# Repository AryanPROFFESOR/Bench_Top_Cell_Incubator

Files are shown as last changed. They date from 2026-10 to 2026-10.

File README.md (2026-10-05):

# Bench-Top Cell Incubator

**An automated stage-top incubator for live-cell imaging of stem cells: custom control PCB, rack-and-pinion plate carriage, firmware and PC dashboard.**

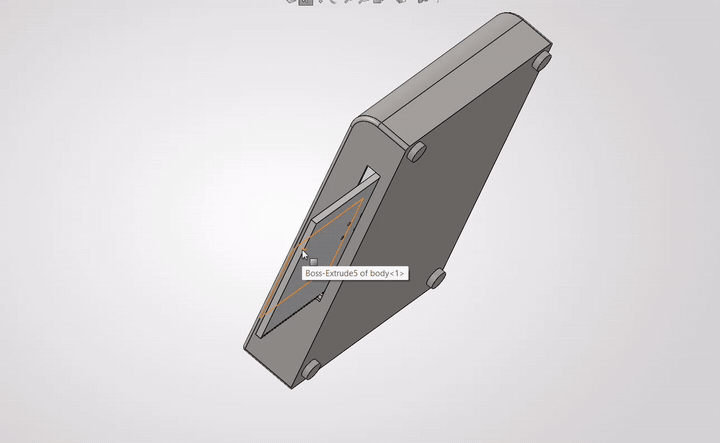
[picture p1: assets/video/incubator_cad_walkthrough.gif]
CAD walkthrough


<sub>SolidWorks walkthrough of the shell, chamber and ejecting tray (loops automatically). [Full-quality video](assets/video/incubator_cad_walkthrough_full.mp4).</sub>

## Contents

- [What this is](#what-this-is)
- [Project status](#project-status)
- [Mechanical design](#mechanical-design)
- [Electronics](#electronics)
  - [System architecture](#system-architecture)
  - [Sensors](#sensors-and-what-they-do)
  - [Communication protocols](#communication-protocols-and-interfaces)
  - [Pin map](#pin-map)
- [Software](#software)
- [Repository layout](#repository-layout)
- [Open questions for the lab](#open-questions-for-the-lab)
- [Fit with the internship brief](#fit-with-the-internship-brief)
- [Known limitations](#known-limitations)
- [Author](#author) · [License](#license)

## What this is

Live-cell time-lapse imaging needs cells held at physiological conditions (37 °C, 5 % CO2, high humidity) on the microscope stage for days.
Full-microscope enclosures are large and expensive. This project is a compact **stage-top incubator** that sits on the stage of an inverted microscope.

Its key feature is an **automated tray**: a motor-driven rack and pinion ejects and retracts a standard 96-well plate, so media changes or robotic liquid handling can happen without disturbing the chamber or the optical alignment.

It was built as a mechatronics and software project in support of an internship application (small cell incubator with temperature, CO2 and N2 control, automatic sample insertion and removal, and C++/Python control software).

## Project status

| Area | Status |
|---|---|
| Control PCB (schematic, DRC) | Complete |
| PCB layout | Routed; ground pour and file export pending |
| Temperature and humidity sensing | Designed |
| 5-channel servo output | Designed |
| Mechanical CAD (SolidWorks) | Almost done; final work waits on lab input (below) |
| Firmware and PC dashboard | Written, sensor maths unit-tested; hardware testing pending |
| CO2 and N2 control | Not on the PCB; assumed external for now |
| Physical build and biological validation | Planned: [validation plan](docs/test_plan.md) |

Full list in [docs/roadmap.md](docs/roadmap.md).

## Mechanical design

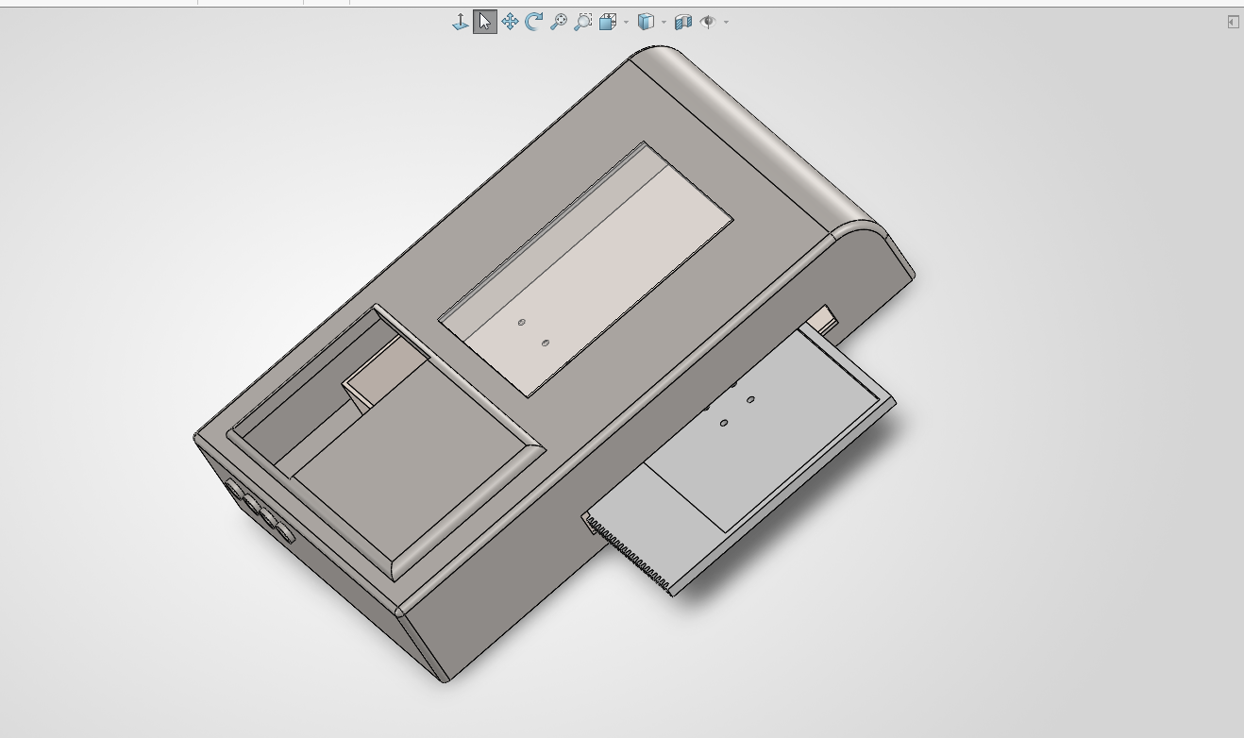
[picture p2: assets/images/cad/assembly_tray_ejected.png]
Assembly with tray ejected


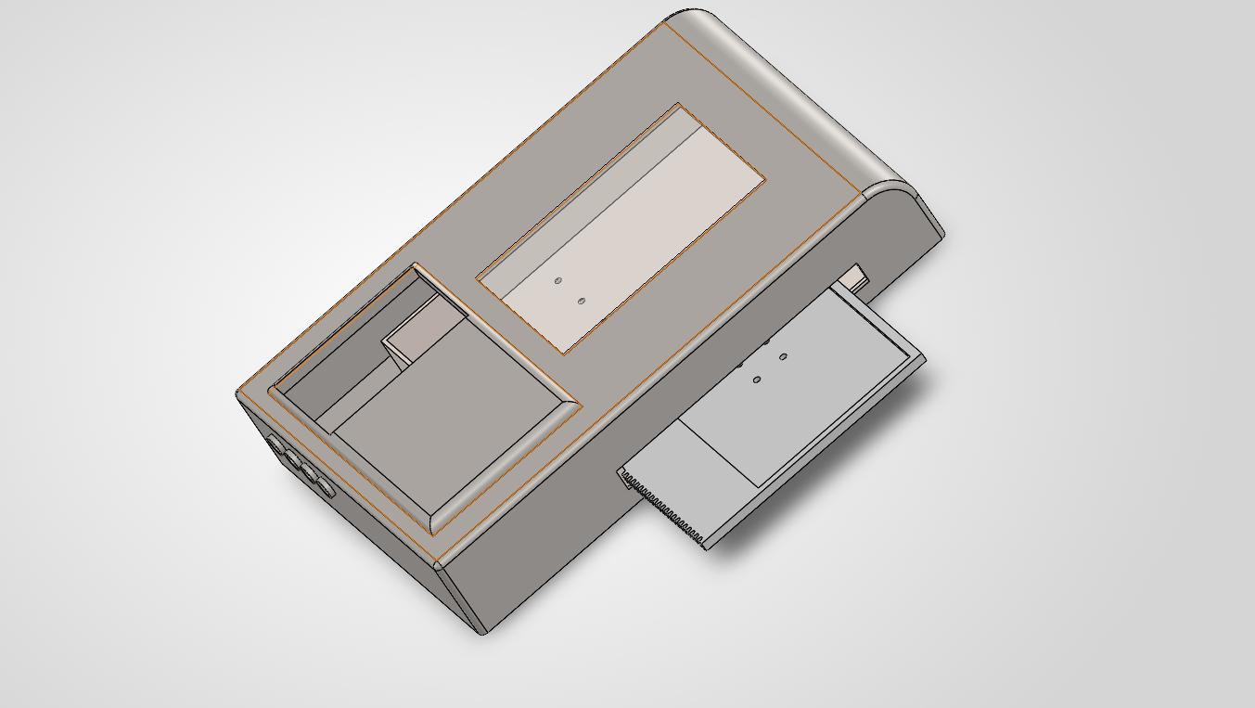
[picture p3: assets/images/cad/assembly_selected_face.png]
Shell with selected top face


| Rack on the carriage tray | Motor bracket and pinion |
|---|---|
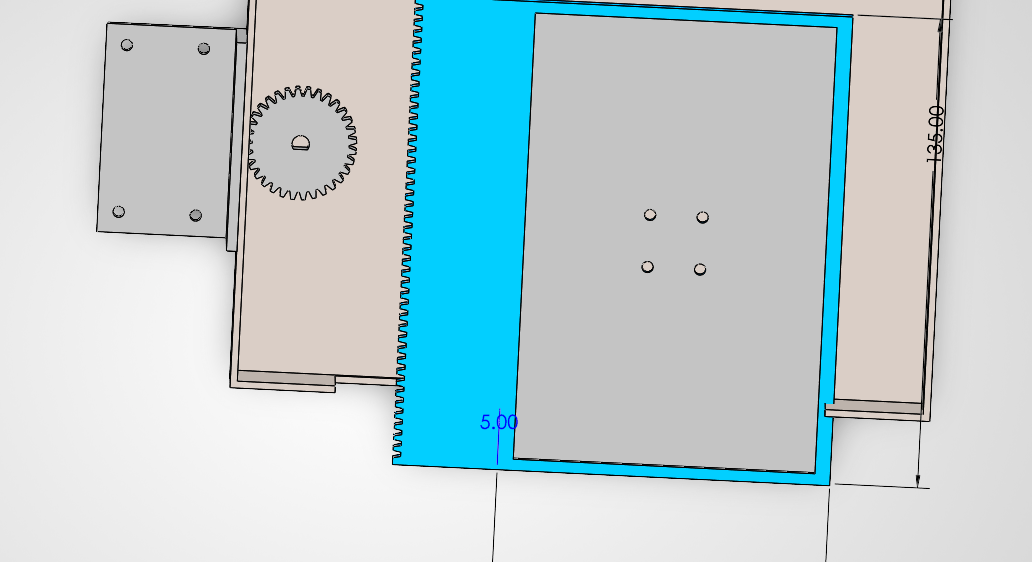
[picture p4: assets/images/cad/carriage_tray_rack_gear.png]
Tray and rack
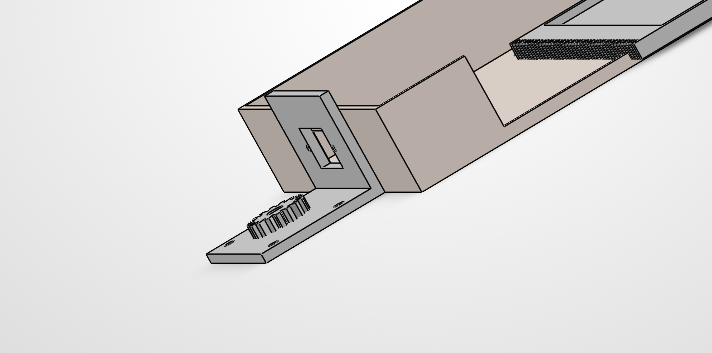
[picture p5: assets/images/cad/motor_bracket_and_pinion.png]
Bracket and pinion
|  |  |

- **Outer shell:** unibody enclosure with an offset viewing window for inverted microscopy, a lateral ejection port and an IEC power switch. An opaque "side-car" cavity keeps the drive and electronics apart from the humid zone.
- **Inner chamber and tray:** the tray holds a 96-well plate and has a linear rack along one edge.
- **Drive:** a pinion meshes with the rack. A motor bracket holds the actuator away from the heated zone.
- **Fabrication:** FDM printing. PETG or ABS for structure, nylon or POM for gears, and a 1 mm polycarbonate or glass window.

Details: [docs/mechanical.md](docs/mechanical.md).

## Electronics

| Routed layout | 3D render |
|---|---|
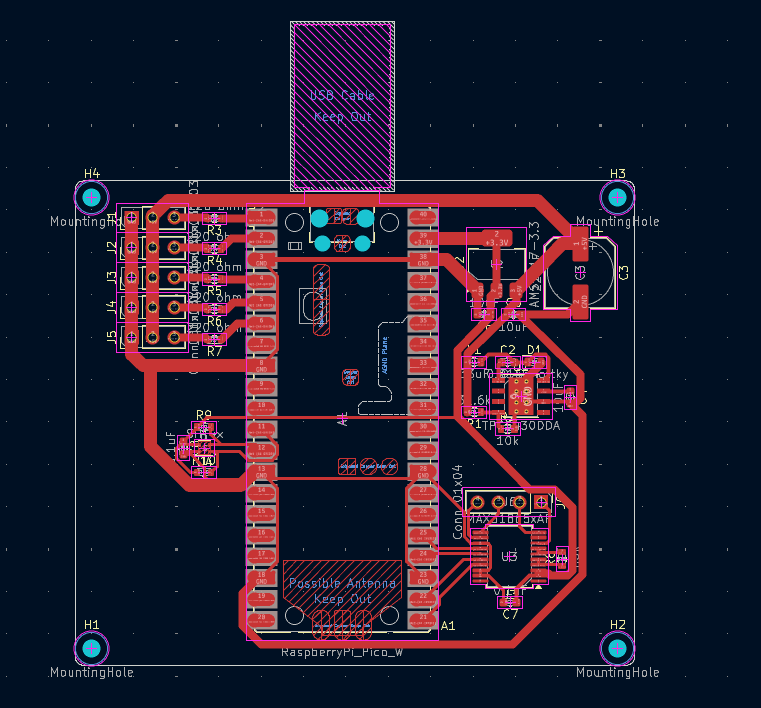
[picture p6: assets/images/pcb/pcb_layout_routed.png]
PCB layout
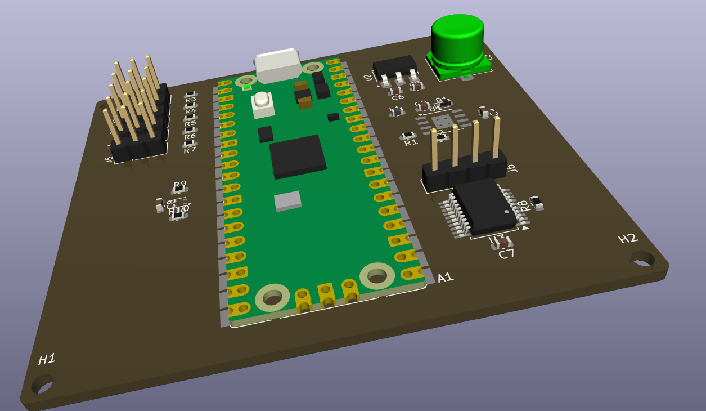
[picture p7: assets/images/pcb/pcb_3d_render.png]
PCB 3D
|  |  |

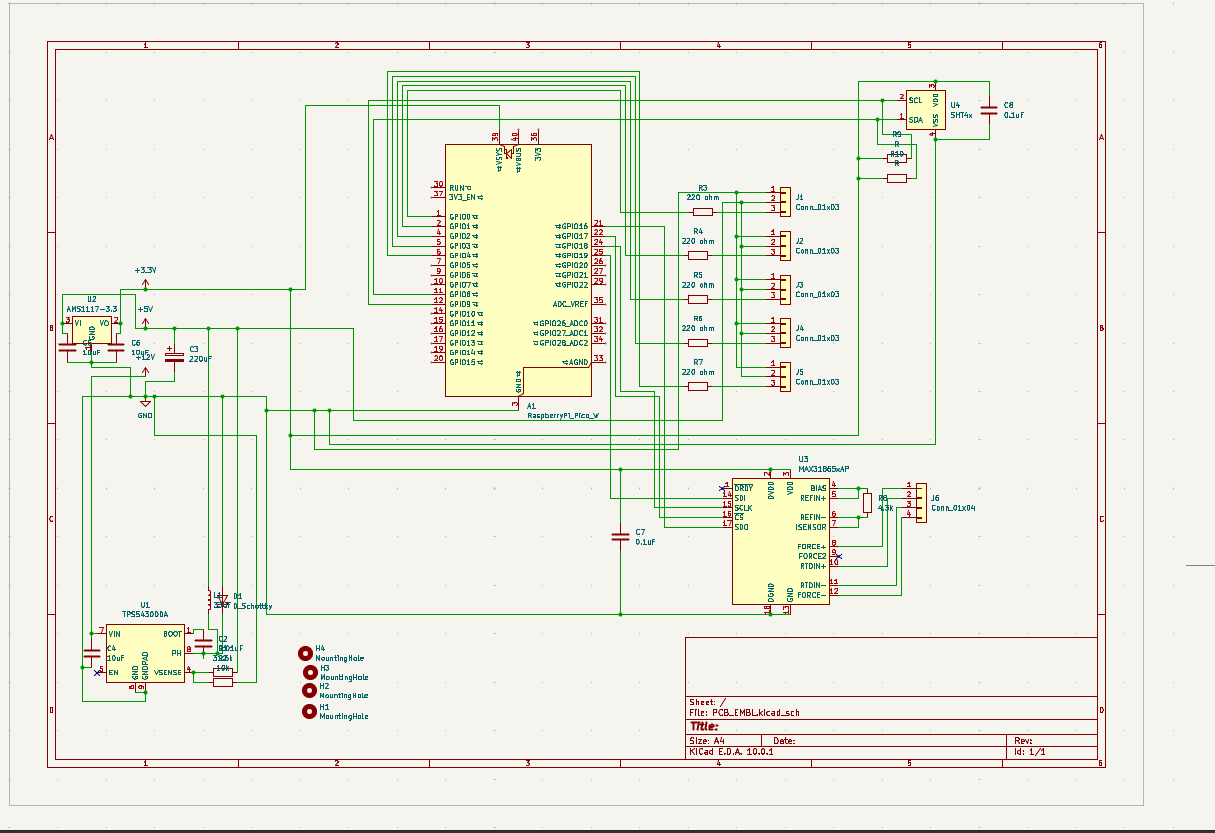
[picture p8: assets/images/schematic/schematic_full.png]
Schematic


The board is built around a **Raspberry Pi Pico W** and powered from 12 V DC through a two-stage supply: a TPS5430 buck converter (5 V, up to 3 A, for actuators) followed by an AMS1117 LDO (3.3 V, for logic and sensors). High-current switching nodes are kept away from the analog sensing area.

### System architecture

Solid arrows are implemented on the current board. Dashed arrows are planned or not yet implemented.

```mermaid
flowchart TB
    subgraph PWR["1. Power"]
        direction LR
        PSU["12 V DC supply<br/>(external)"] --> BUCK["TPS5430 buck<br/>12 V to 5 V, up to 3 A"]
        BUCK --> LDO["AMS1117 LDO<br/>5 V to 3.3 V"]
    end

    subgraph SENSE["2. Sensing"]
        direction TB
        PT["PT1000 probe<br/>4-wire, header J6"] -->|"analog resistance"| MAX["MAX31865<br/>RTD-to-digital"]
        SHT["SHT4x<br/>humidity + temperature"]
    end

    subgraph CTRL["3. Controller"]
        PICO["Raspberry Pi Pico W<br/>MicroPython firmware"]
    end

    subgraph ACT["4. Actuation"]
        SERVO["Servo headers J1 to J5<br/>J1 drives the rack-and-pinion tray"]
    end

    subgraph HOST["5. Host"]
        PC["PC dashboard<br/>PyQt5 + CSV log"]
    end

    subgraph EXT["Planned, not on this PCB"]
        direction TB
        CO2["CO2 sensor + gas control"]
        N2["N2 valve"]
        HEAT["Heater + driver stage"]
    end

    LDO -->|"3.3 V"| PICO
    LDO -->|"3.3 V"| MAX
    LDO -->|"3.3 V"| SHT
    BUCK -->|"5 V"| SERVO

    MAX <-->|"SPI0, GPIO16-19"| PICO
    SHT <-->|"I2C0, GPIO8/9, addr 0x44"| PICO
    PICO -->|"PWM 50 Hz, GPIO0-4"| SERVO
    PICO <-->|"USB serial, 115200 baud, JSON lines"| PC

    PICO -.->|"Wi-Fi telemetry (hardware ready, firmware pending)"| PC
    PICO -.->|"protocol TBD"| CO2
    PICO -.->|"GPIO / PWM"| N2
    PICO -.->|"PWM / on-off"| HEAT
```

### Sensors and what they do

| Sensor | Measures | Details |
|---|---|---|
| PT1000 RTD + MAX31865 | Chamber temperature (target 37.0 °C) | 4-wire ratiometric measurement removes lead-wire error; 4.3 kΩ 0.1 % reference resistor |
| SHT4x | Relative humidity (target about 95 %) and temperature | Digital and factory-calibrated, ±1.5 % RH typical |
| CO2 sensor (planned) | 5 % CO2 | Depends on the gas route |
| N2 / O2 (planned) | Hypoxia control | Depends on the gas route |

### Communication protocols and interfaces

| Link | Protocol | Pins / port | Settings and details |
|---|---|---|---|
| Pico W ↔ MAX31865 | **SPI** (mode 1: CPOL 0, CPHA 1) | SPI0: MISO GPIO16, CS GPIO17, SCK GPIO18, MOSI GPIO19 | 500 kHz in firmware (chip supports up to 5 MHz); 15-bit ADC read from RTD registers; 50 Hz mains filter enabled |
| PT1000 → MAX31865 | **Analog**, 4-wire Kelvin sensing | Header J6 (FORCE+, FORCE−, RTDIN+, RTDIN−) | Ratiometric against R8 = 4.3 kΩ; temperature from the Callendar-Van Dusen equation |
| Pico W ↔ SHT4x | **I2C** | I2C0: SDA GPIO8, SCL GPIO9 | Address 0x44; 100 kHz; 10 kΩ pull-ups (R9, R10) to 3.3 V; CRC-8 check on every reading |
| Pico W → servos | **PWM** | GPIO0 to GPIO4, headers J1 to J5 | 50 Hz, 500 to 2500 µs pulse; 220 Ω series resistor on each signal line |
| Pico W ↔ PC | **USB serial** (CDC virtual COM port) | Pico micro-USB | 115200 baud; Pico sends one JSON line per sample; PC sends text commands `EJECT`, `RETRACT`, `SET_TEMP <°C>` |
| Pico W ↔ network | **Wi-Fi** (on-board radio) | Antenna keep-out on the PCB | Hardware supports it; telemetry over Wi-Fi is not implemented yet |
| CO2 / N2 / heater | To be decided | Not on this PCB | Depends on the sensors, valves and driver chosen (see [roadmap](docs/roadmap.md)) |
| Power | **12 V DC → 5 V → 3.3 V** | 5 V rail for servos, 3.3 V for logic and sensors | Buck then LDO, so sensors are isolated from motor noise |

Example telemetry line sent by the firmware:

```json
{"t": 1767225600, "tray": "retracted", "setpoint_c": 37.0, "temp_c": 36.982, "heater": 0.0, "rh_pct": 94.6}
```

### Pin map

| Function | Pico W pin |
|---|---|
| SPI (MAX31865): MISO / CS / SCK / MOSI | GPIO16 / 17 / 18 / 19 |
| I2C (SHT4x): SDA / SCL | GPIO8 / 9 |
| Servo PWM, headers J1 to J5 | GPIO0 to GPIO4 (220 Ω series resistors) |

More in [docs/electronics.md](docs/electronics.md); parts list in [hardware/pcb/bom.csv](hardware/pcb/bom.csv); PCB documentation PDF in [hardware/pcb/docs/](hardware/pcb/docs/).

## Software

- **Firmware** (`firmware/pico/`, MicroPython): MAX31865 and SHT4x drivers, servo-driven tray eject/retract with a smooth ramp, a PID loop (heater output is optional because the board has no heater driver yet), and JSON telemetry over USB serial.
- **Dashboard** (`software/gui/`, PyQt5): live temperature and humidity, tray control, setpoint, CSV logging.
- **Tests** (`firmware/tests/`): the PT1000 conversion, SHT4x CRC and conversion, and PID clamping run on a PC.

```bash
# unit tests (no hardware needed)
python -m unittest discover firmware/tests

# flash firmware: copy firmware/pico/*.py to the Pico W (for example with mpremote or Thonny), then:
pip install -r software/requirements.txt
python software/gui/incubator_gui.py --port COM5      # or /dev/ttyACM0
```

Heads-up: the firmware and dashboard have not yet been run on the assembled hardware. Tray angles and PID gains in `config.py` and `main.py` are placeholders to calibrate.

## Repository layout

```text
assets/        images and the CAD walkthrough video (GIF + MP4)
docs/          electronics, mechanical, test plan, roadmap, design review notes
hardware/
  pcb/         KiCad project and schematic, BOM, PCB documentation PDF
  cad/         SolidWorks assembly and design proposal PDF
firmware/      MicroPython code for the Pico W, plus PC unit tests
software/      PyQt5 dashboard (and a placeholder for the image pipeline)
```

## Open questions for the lab

These three answers decide the final CAD ([details](docs/roadmap.md)):

1. Should the incubator be screwed to the microscope stage, or rest on it?
2. How are CO2 and N2 supplied: an existing external mixer (fittings only), or valves controlled by this device?
3. Should the control PCB live inside the side-car cavity, or in an external control box?

## Fit with the internship brief

| Requirement | Where it shows up here |
|---|---|
| Design a small incubator (temperature, CO2, N2) | Temperature and humidity sensing and the chamber design are done; CO2/N2 are scoped as external ([roadmap](docs/roadmap.md)) |
| Automatic sample insertion and removal | Rack-and-pinion tray CAD and servo tray control |
| Control software in C++ and Python | MicroPython firmware and a PyQt5 dashboard (C++/Arduino version is a possible port) |
| Electronics and soldering | Custom KiCad PCB with buck, LDO, RTD front-end and I2C sensor |
| 3D design and printing | SolidWorks assembly with an FDM print plan |
| Test with biological samples over days | [Validation plan](docs/test_plan.md) |
| Work with biologists | The open questions above are written for the lab |

Stepper motors: the current board drives hobby servos. A stepper-based tray drive is listed as the next step in the [roadmap](docs/roadmap.md).

## Known limitations

A self-review of the current schematic is in [docs/design_review_notes.md](docs/design_review_notes.md).

## Author

Aryan, ECE student at USICT. GitHub: [@AryanPROFFESOR](https://github.com/AryanPROFFESOR).

## License

[MIT](LICENSE)

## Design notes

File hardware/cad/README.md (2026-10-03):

# CAD (SolidWorks)

- `solidworks/Main_Incubator_Assembly.SLDASM` is the top-level assembly.
- An assembly file only references its parts. To open it in full, add the part files (`.SLDPRT`) into `solidworks/` next to it.
- Also export STEP and STL files for the shell, chamber, tray, bracket and gears so the design can be viewed and printed without SolidWorks.
- `Mechanical_Design_Proposal.pdf` has the design write-up.

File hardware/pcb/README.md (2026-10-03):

# Control PCB (KiCad 10)

- `kicad/PCB_EMBL.kicad_pro` and `kicad/PCB_EMBL.kicad_sch`: project and schematic.
- `docs/PCB_Hardware_Documentation.pdf`: component-by-component documentation.
- Layout images: `../../assets/images/pcb/`.

**Pending:** the routed board file `PCB_EMBL.kicad_pcb` is not in this repo yet. Save it from KiCad's PCB editor and copy it into `kicad/`, together with Gerbers and a BOM export (`File > Fabrication Outputs`).

Bill of materials: [`bom.csv`](bom.csv).

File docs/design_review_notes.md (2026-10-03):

# Design review notes (checklist for the next revision)

A self-review of the current schematic. Items are things to confirm or fix before ordering boards.

| # | Item | Why it matters |
|---|---|---|
| 1 | L1 is labelled `33uF` in the schematic; it should read 33 uH. | Wrong unit in the schematic value field. |
| 2 | L1 and D1 use 0603 footprints. | A 0603 inductor and diode cannot carry the buck's current at up to 3 A. Select a power inductor and a Schottky in a proper package (for example SMA/SMB) and update the footprints. Check values against the TPS5430 datasheet. |
| 3 | R9 and R10 (I2C pull-ups) have the value `R` in the schematic; the documentation says 10 kohm. | Set the value so the BOM is correct. |
| 4 | No 12 V input connector, fuse or reverse-polarity protection is in the schematic. | Add a terminal block, fuse and TVS or reverse protection. |
| 5 | No heater driver. | Temperature regulation needs an output stage (MOSFET or SSR) for the heater. |
| 6 | Five servos share one 5 V, 3 A rail with the logic supply. | Check the combined stall current; consider limiting how many servos run at once. |
| 7 | The layout figure is labelled "prior to ground plane pour". | Complete the pour and re-run DRC before fabrication. |
| 8 | SHT4x is a 1.5 x 1.5 mm DFN. | Very hard to hand-solder; consider a reflow stencil or a breakout. |
| 9 | `PCB_EMBL.kicad_pcb` was empty (79 bytes) in the exported project. | Save the layout in KiCad and add the file to `hardware/pcb/kicad/`. |

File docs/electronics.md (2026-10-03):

# Electronics: control PCB

Source: `hardware/pcb/kicad/` (KiCad 10 schematic and project) and `hardware/pcb/docs/PCB_Hardware_Documentation.pdf`.

Schematic

## Block diagram

```mermaid
flowchart LR
    PSU[12 V DC input] --> BUCK[TPS5430 buck<br/>12 V to 5 V, up to 3 A]
    BUCK --> RAIL5[5 V rail]
    RAIL5 --> LDO[AMS1117-3.3 LDO]
    LDO --> RAIL33[3.3 V rail]
    RAIL5 --> SERVOS[J1-J5 servo headers]
    RAIL33 --> PICO[Raspberry Pi Pico W]
    RAIL33 --> MAX[MAX31865 RTD converter]
    RAIL33 --> SHT[SHT4x humidity sensor]
    PT[PT1000 probe, 4-wire] --> MAX
    MAX -- SPI0 --> PICO
    SHT -- I2C0 --> PICO
    PICO -- 5x PWM, 220 ohm series --> SERVOS
    PICO -. Wi-Fi / USB serial .-> PC[PC dashboard]
```

## Microcontroller
Raspberry Pi Pico W (A1): PWM for the actuators, SPI/I2C sensor reads, USB serial and Wi-Fi telemetry.

## Pin map

| Function | Pico W pin | Connected to |
|---|---|---|
| SPI0 MISO | GPIO16 | MAX31865 SDO |
| SPI0 CS | GPIO17 | MAX31865 CS |
| SPI0 SCK | GPIO18 | MAX31865 SCLK |
| SPI0 MOSI | GPIO19 | MAX31865 SDI |
| I2C0 SDA | GPIO8 | SHT4x SDA (10 k pull-up) |
| I2C0 SCL | GPIO9 | SHT4x SCL (10 k pull-up) |
| PWM 1-5 | GPIO0-GPIO4 | J1-J5 signal pin, each through 220 ohm (R3-R7) |

## Sensors and what each one is for

| Sensor | Part | Measures | Why this part | Interface |
|---|---|---|---|---|
| Chamber temperature | PT1000 Class A RTD + MAX31865 (U3) | Temperature at the 37.0 C target | Linear, stable, and 4-wire sensing removes lead-wire error. A 4.3 kohm 0.1 % reference resistor (R8) sets the ratiometric scale for a PT1000. | SPI0, header J6 |
| Humidity | Sensirion SHT4x (U4) | Relative humidity (target about 95 %) and a second temperature reading | Digital, factory-calibrated, typical RH accuracy +/-1.5 %. | I2C0, address 0x44 |
| CO2 (planned, external) | not selected | 5 % CO2 target | Needs a decision on the gas route (see [roadmap](roadmap.md)). | not on this PCB |
| N2 (planned, external) | not selected | Hypoxia / O2 displacement | Same dependency as CO2. | not on this PCB |

## Power architecture

| Stage | Part | Role | Key passives |
|---|---|---|---|
| 1 | TPS5430DDA buck (U1) | 12 V to 5 V, up to 3 A, for the actuators | C4 10 uF input, C2 0.01 uF bootstrap, D1 Schottky catch diode, L1 33 uH, C3 220 uF output |
| 2 | AMS1117-3.3 LDO (U2) | Clean 3.3 V for logic and sensors, kept away from the motor rail | C5 10 uF in, C6 10 uF out |

Feedback divider R1 31.6 kohm / R2 10 kohm sets the buck output near 5 V (1.221 V reference x (1 + 31.6/10) is about 5.08 V).
Local decoupling: C7 0.1 uF on the MAX31865, C8 0.1 uF on the SHT4x.

## Layout intent
High-current switching nodes (buck, inductor, diode) are kept physically apart from the analog RTD front-end. A USB keep-out and a Wi-Fi antenna keep-out are respected around the Pico W module.
See `assets/images/pcb/` for the routed layout and 3D render.

## Servo outputs
J1-J5 are 3-pin headers (5 V, GND, signal). The 220 ohm series resistor limits current into the Pico GPIO if a servo signal line misbehaves.

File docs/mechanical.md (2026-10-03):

# Mechanical design

CAD: SolidWorks 2026 (`hardware/cad/solidworks/Main_Incubator_Assembly.SLDASM`).
The assembly references part files that are not in this repo yet; see `hardware/cad/README.md`.
Design write-up: `hardware/cad/Mechanical_Design_Proposal.pdf`.

Assembly with tray ejected

## Concept
A stage-top incubator that sits on an inverted microscope stage and holds mammalian cell cultures at physiological conditions while imaging.
The main feature is a rack-and-pinion carriage: a standard 96-well plate can be ejected and retracted by a motor,
so media can be changed (manually or by a liquid-handling robot) without opening the chamber to room air.

## Parts

| Part | Description |
|---|---|
| Motor bracket | L-shaped bracket, four mounting holes, keeps the actuator away from the heated zone. |
| Inner chamber base and carriage tray | Containment floor with a sliding tray for a 96-well plate. The tray has an integrated linear rack along one edge. |
| Drive | Rotary pinion meshing with the tray rack, turning rotation into linear tray travel. |
| Outer shell and internal cavity | Unibody enclosure with an offset viewing window (for inverted microscopy), a lateral ejection port and an IEC power switch module. The opaque section forms a "side-car" cavity that separates drive and electronics from the humid zone. |
| Optical window | 1 mm polycarbonate or glass insert, cut and sealed by hand. Clear FDM filament is not used because it lacks the optical quality. |

| | |
|---|---|
| Bracket and pinion | Tray and rack |

## Fabrication plan (FDM)
- Shell, chamber, bracket: PETG or ABS (stable at a sustained 37 C).
- Gears: nylon or POM (acetal) for low friction and wear.
- Window: 1 mm polycarbonate or glass, sealed.

## Open mechanical decisions
1. Mount to the microscope stage with screws/flanges, or rest passively on the translation stage?
2. Gas routing: push-to-connect fittings to an external CO2/N2 mixer, or on-board valves?
3. Electronics: inside the side-car cavity, or in an external control box?

These are tracked in [roadmap.md](roadmap.md).

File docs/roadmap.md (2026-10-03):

# Roadmap and open questions

## Status

| Area | Status |
|---|---|
| Control PCB schematic | Complete, DRC clean (per hardware documentation) |
| PCB layout | Routed; final ground-plane pour and export pending |
| Temperature and humidity sensing | Designed (PT1000 + MAX31865, SHT4x) |
| Servo outputs | 5 channels, designed |
| Reference firmware | Written; sensor maths unit-tested on a PC; not yet run on hardware |
| PC dashboard | Written; not yet run against hardware |
| CAD (SolidWorks) | Shell, chamber, tray, rack and pinion, bracket modelled; final work pending |
| CO2 and N2 control | Not on the PCB. Assumed external for now |
| Heater drive | Not on the PCB. Needs an external driver stage |

## Questions to settle with the lab (these block the CAD finalisation)
1. **Microscope mounting.** Is the incubator hard-mounted on the stage, or does it rest on it?
2. **Gas routing.** Is there an existing CO2/N2 mixer to tap (push-to-connect fittings only), or should the device switch the gas itself with valves?
3. **Electronics placement.** Inside the side-car cavity, or in an external desktop box?

## Next steps
- Finalise CAD once the three answers are known; add flanges or dovetails for the stage.
- Choose a heater (for example a film heater with a MOSFET or SSR stage) and a CO2 sensor.
- Choose the actuator for the tray: the current board drives hobby servos. A stepper (for example NEMA 17 with a driver module) would give more precise open-loop positioning and unlimited rotation; this would need a driver and limit-switch inputs.
- Print, assemble and run the [validation plan](test_plan.md).
- Add automatic image transfer to a server, remote access and image analysis (see `software/pipeline/`).

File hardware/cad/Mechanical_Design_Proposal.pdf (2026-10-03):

## Preliminary Design Proposal: Automated Stage-Top Incubator for Live-Cell Imaging

## 1. System Overview & Purpose

This document details the mechanical specifications and rapid-prototyping pipeline for an automated stage-top live-cell incubator. The purpose of this device is to maintain strict physiological conditions (37◦C, 5% CO2, high humidity) for mammalian cell cultures directly on the stage of an inverted microscope, enabling long-term, time-lapse imaging without requiring a massive, expensive full-microscope enclosure.

The core feature of this design is an automated rack-and-pinion carriage mechanism that allows a standard 96-well microplate to be programmatically ejected and retracted. This enables seamless robotic liquid handling or manual media changes without disrupting the internal thermal environment or optical alignment.

## 2. Mechanical Design & Assembly

The structural assembly is engineered for modularity. It consists of five primary components:

- Motor Bracket: An L-shaped mounting fixture featuring four through-holes to secure the actuator away from the heated biological zone.

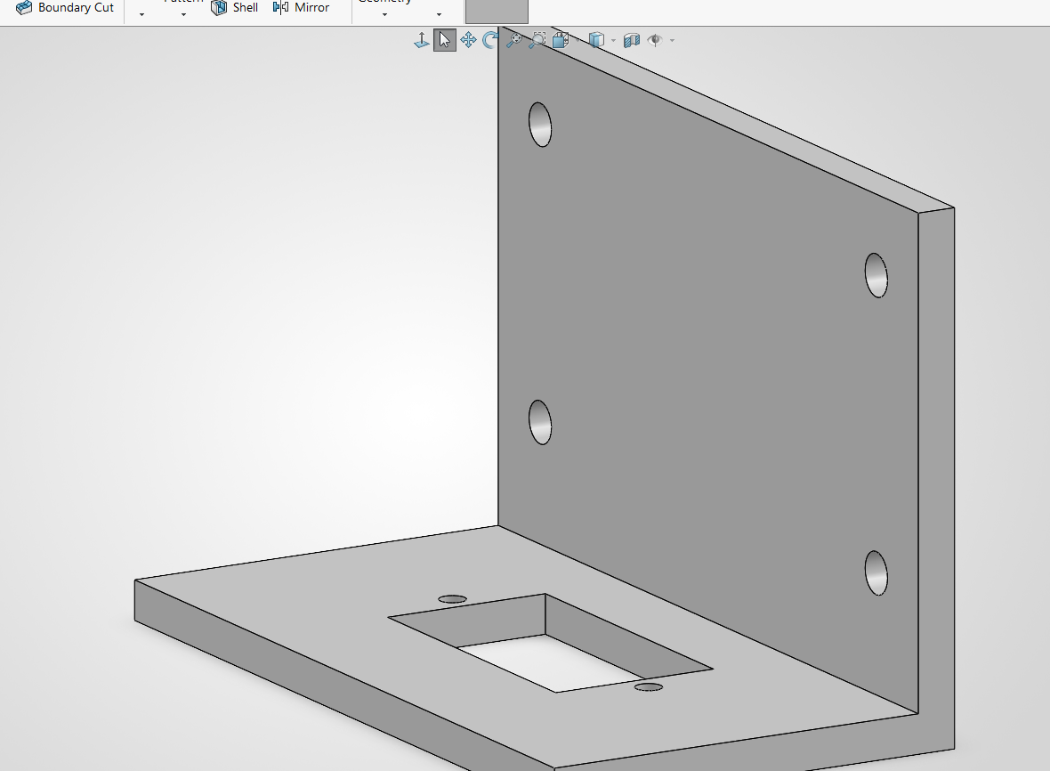
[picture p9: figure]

- Inner Chamber Base & Carriage Tray: The primary containment floor houses the sliding carriage tray. The tray accommodates a standard 96-well microplate and features an integrated linear rack gear along the longitudinal edge for automated ejection and retraction.
- Drive Mechanism: A rotary pinion gear meshes with the carriage tray’s rack gear, translating rotary motor output into precise linear translation of the cell cultures.

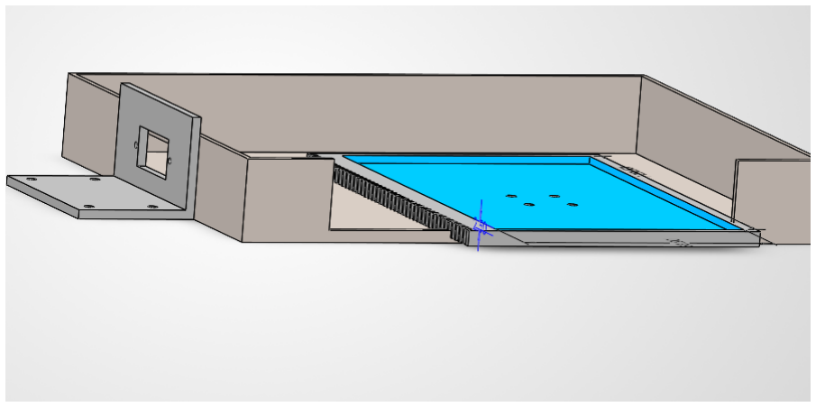
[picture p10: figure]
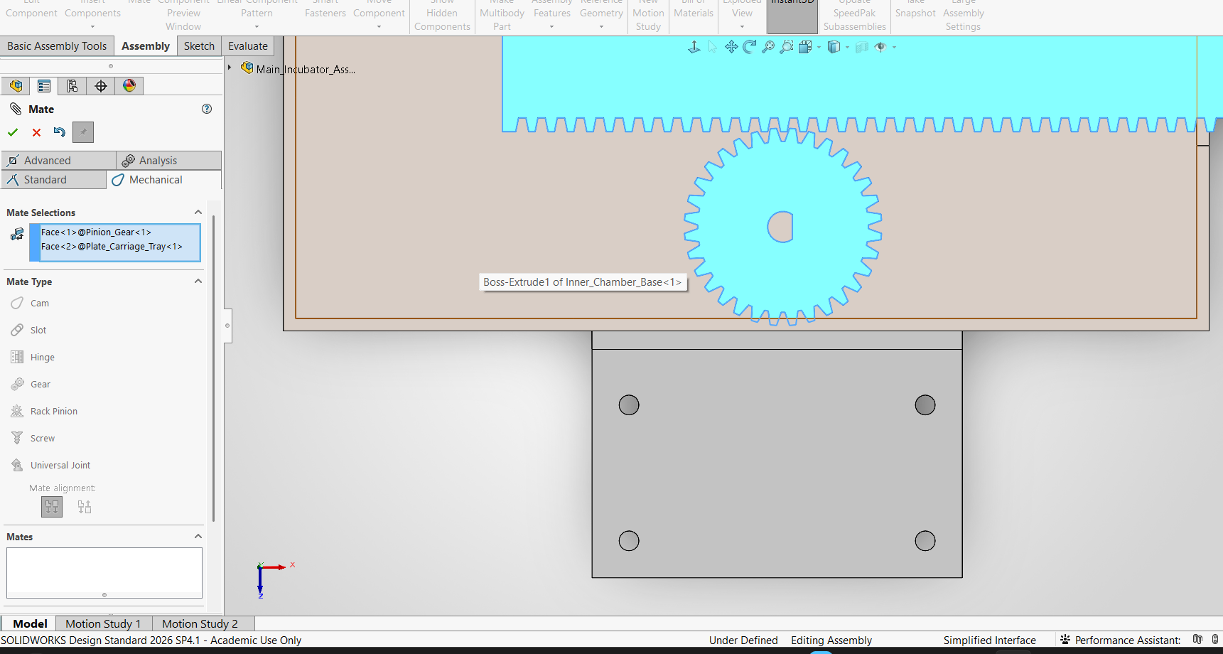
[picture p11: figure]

- Outer Shell & Internal Cavity: A unibody enclosure featuring an offset rectangular viewing window (aligned for inverted microscopy), a lateral ejection port, and an IEC power switch module. The solid, opaque section of the shell forms an internal “side-car” cavity. This isolates the mechanical drive and potential control electronics from the humidified incubation zone.

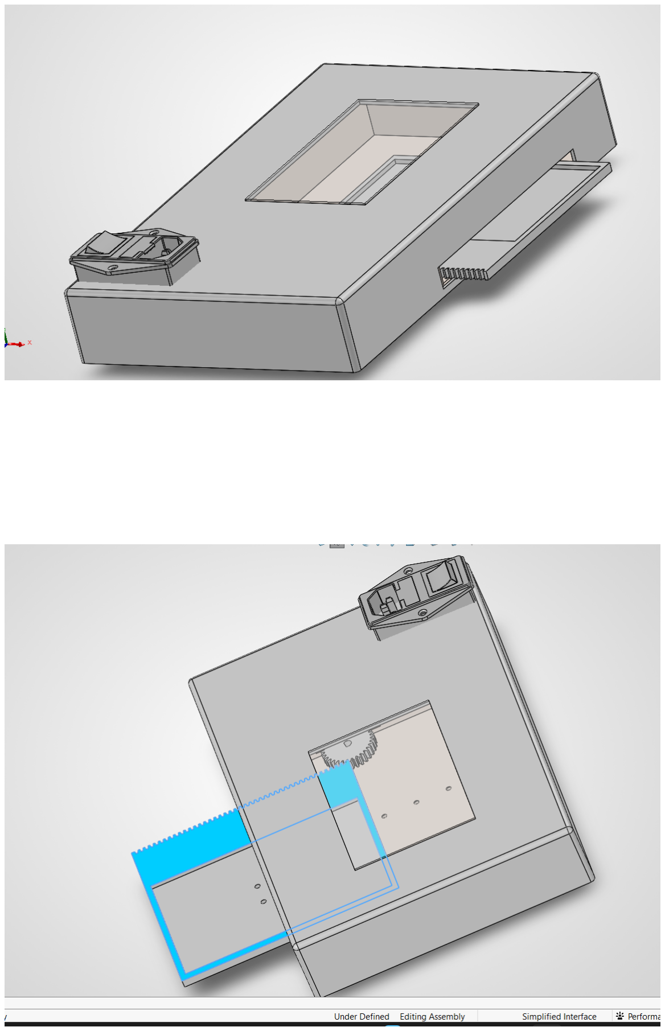
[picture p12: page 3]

## 3. Manufacturing & Fabrication Plan

To ensure this hardware can be deployed rapidly on-site, the entire structural chassis is optimized for Fused Deposition Modeling (FDM) 3D printing. This eliminates lead times associated with CNC machining and allows for overnight geometric iterations.

- Structural Components (Shell, Chamber, Bracket): Fabricated on-site using PETG or ABS filament. These thermoplastics provide the necessary thermal stability to prevent warping under sustained 37◦C incubation conditions.
- Drive Components (Gears): Printed in Nylon or POM (Acetal) to ensure low friction and high wear resistance during continuous automated oscillations.
- Optical Window: A 1mm insert of clear polycarbonate or standard silicate glass will be manually cut and sealed. FDM transparent filaments will not be used, as they lack the optical clarity required for highresolution inverted microscopy.

## 4. Two-Month On-Site Hardware Implementation Timeline

The following 8-week timeline is designed to aggressively finalize and assemble the physical hardware. Completing the mechanical build within this two-month window ensures that subsequent time is entirely dedicated to software tuning, PCB reprogramming, and rigorous validation via live-cell assays.

- Weeks 1–2: Dimensional Verification & CAD Finalization
Measure the specific inverted microscope translation stage. Modify the inner chamber base CAD to include exact mounting flanges or dovetail grooves. Finalize the internal cavity dimensions based on the chosen microcontroller footprint.
- Weeks 3–4: Rapid Prototyping & Mechanical Assembly
FDM print the inner chamber, motor bracket, and carriage tray in PETG. Print the rack and pinion gears in Nylon. Assemble the drive mechanism and physically verify smooth, jam-free linear translation of the tray.
- Weeks 5–6: Outer Shell Fabrication & Subsystem Integration
Print the unibody outer shell. Install the motor, limit switches, IEC power socket, and physically mount the custom PCB inside the side-car cavity. Tap pneumatic ports for CO2/N2 gas lines and install the glass optical window.
- Weeks 7–8: Environmental Calibration & System Handover
Seal the chamber and conduct initial dry runs. Validate that the internal chamber reaches and holds 37◦C without deforming the plastics. Hand over the completed physical hardware for the secondary project phase: PCB firmware tuning, UI software development, and live-cell testing.

## 5. Open Integration Dependencies

Before Week 1 commences, the following three parameters must be finalized with the laboratory:

1. Microscope Placement: Does the target microscope require the incubator to be hard-mounted via screws/flanges, or will it rest passively on the translation stage?
2. Gas Routing (CO2/N2): Will the system tap into an existing external pneumatic mixer, requiring only push-to-connect tube fittings on the shell?

3. Control Electronics: Should the custom mechatronic PCB be housed internally within the shell’s side-car cavity, or routed to an external desktop control box?

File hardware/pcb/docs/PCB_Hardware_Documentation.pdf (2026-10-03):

## Hardware Documentation: Stage-Top Bioreactor Control PCB

Aryan

## Project Objective

This document details the custom printed circuit board (PCB) designed to control an automated stage-top bioreactor. The system is engineered to provide precise environmental regulation and mechatronic actuation required for mammalian cell culture, tissue handling, and 3D organoid generation.

## 1 Hardware Status

The core PCB design is complete, and all design rule checks (DRC) have been successfully verified. All electrical errors have been resolved, with high-current switching nodes physically isolated from precision analog sensing zones. No further schematic modifications will be made to this baseline control board. Future hardware revisions will be strictly limited to the integration of external CO2 and N2 gas regulation manifolds, should those modules require direct PCB control rather than standalone drivers.


Figure 1: Finalized system schematic showing completely resolved electrical connections.

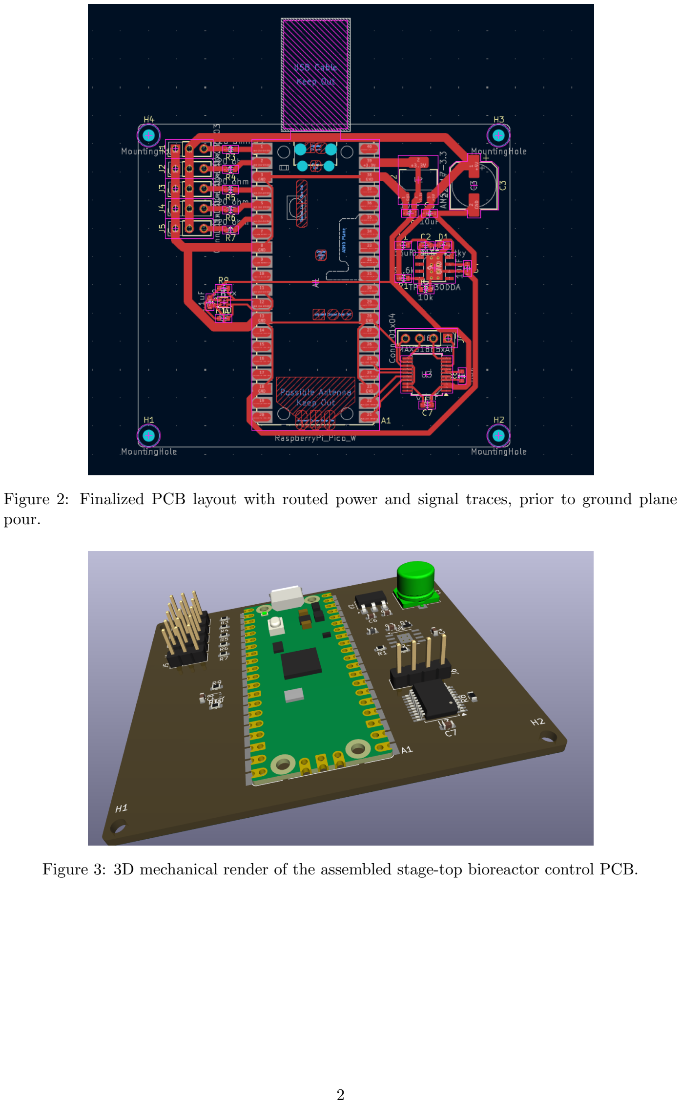
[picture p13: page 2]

Figure 2: Finalized PCB layout with routed power and signal traces, prior to ground plane pour.

Figure 3: 3D mechanical render of the assembled stage-top bioreactor control PCB.

## 2 Microcontroller

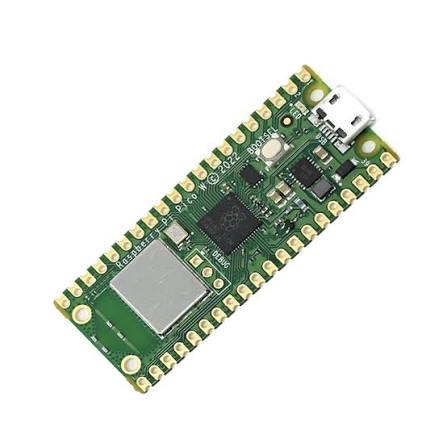
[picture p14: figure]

Figure 4: Raspberry Pi Pico W microcontroller module.

The central processing unit is the Raspberry Pi Pico W (A1). It handles all PWM generation for the servo motors, I

2C/SPI sensor communication, and wireless telemetry for bioreactor monitoring.

## 3 Sensor Specifications

### 3.1 Temperature Regulation (MAX31865 & PT1000)

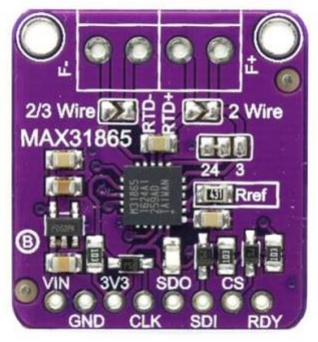
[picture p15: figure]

Figure 5: MAX31865 RTD-to-Digital Converter.

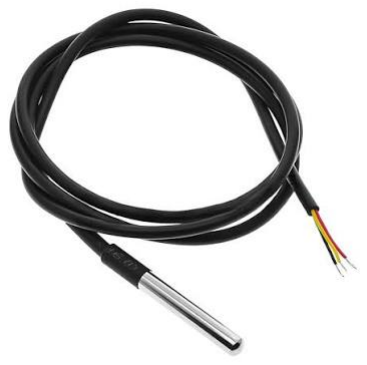
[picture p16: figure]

Figure 6: PT1000 Platinum Resistance Thermometer probe.

High-precision thermal measurement for the 37.0

◦C biological target is handled by the MAX31865 RTD-to-Digital Converter (U3).

[noitemsep,topsep=0pt]

- Probe: Interface designed for a Class A PT1000 Platinum Resistance Temperature Detector via a 4-pin screw terminal (J6). The PT1000 has a nominal resistance of 1000 Ω at 0◦C and provides highly linear resistance changes proportional to temperature.
- Topology: 4-wire ratiometric configuration (FORCE+, FORCE-, RTDIN+, RTDIN-) to completely eliminate lead-wire resistance errors.
- Reference Resistor: 4.3 kΩ (0.1% tolerance) precision resistor (R8) bridging the BIAS and REFIN+ pins to define the ADC reference voltage.
- Data Interface: SPI bus connected to Pico W GPIO16 (MISO), GPIO17 (CS), GPIO18 (SCLK), and GPIO19 (MOSI).

### 3.2 Ambient Humidity (SHT4x)

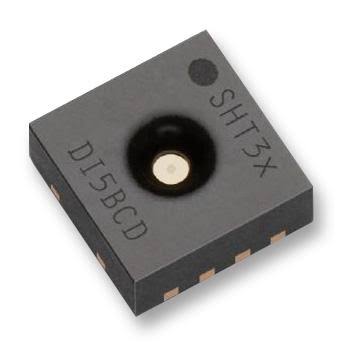
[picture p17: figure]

Figure 7: SHT4x series digital temperature and humidity sensor package.

Relative humidity monitoring to maintain the 95% RH incubator environment is handled by the SHT4x digital sensor (U4).

[noitemsep,topsep=0pt]

- Range & Accuracy: Operating range of 0 . . . 100% Relative Humidity and −40 . . . 125◦C. Typical RH accuracy is ±1.5%.
- Data Interface: I
2C bus connected to Pico W GPIO8 (SDA) and GPIO9 (SCL).
- Pull-ups: 10 kΩ pull-up resistors (R9, R10) referencing the 3.3V logic rail.

## 4 Power Architecture & Capacitance Matrix

The board utilizes a dual-stage power regulation system to drop a 12V DC input to a 5V high-current rail for actuation, and a filtered 3.3V logic rail for the microcontroller and sensors.

### 4.1 Stage 1: 5V Buck Converter (TPS5430DDA)

Handles the primary voltage step-down and supplies up to 3A for the servo motors.

[noitemsep,topsep=0pt]

- C4 (10 µF SMD): Input decoupling capacitor placed flush against VIN and GND pins to absorb 12V high-frequency transient switching spikes.
- C2 (0.01 µF SMD): Bootstrap capacitor bridging BOOT and PH pins to drive the internal high-side MOSFET.
- D1 (Schottky Diode): Catch diode to provide a current path during the switch off-time.
- L1 (33 µH SMD): Primary energy storage inductor.
- C3 (220 µF Electrolytic): Bulk output filter capacitor placed immediately after L1 to smooth switching ripples and provide instantaneous current during sudden servo actuation.

### 4.2 Stage 2: 3.3V Linear Regulator (AMS1117-3.3)

Provides a clean, low-noise voltage supply isolated from the motor rails.

[noitemsep,topsep=0pt]

- C5 (10 µF SMD): Input filter capacitor to strip residual buck converter switching noise from the 5V line before it enters the LDO.

- C6 (10 µF SMD): Output stability capacitor to prevent internal LDO oscillation under changing digital loads.

### 4.3 Sensor Decoupling Capacitors

[noitemsep,topsep=0pt]

- C7 (0.1 µF SMD): High-frequency local decoupling capacitor placed directly across the VDD and GND pins of the MAX31865 (U3) to shunt noise and ensure precision analog measurements.
- C8 (0.1 µF SMD): High-frequency local decoupling capacitor placed directly across the VDD and VSS pins of the SHT4x (U4).

## 5 Mechatronic Actuation

Stage-top mechanical actuation is driven by five PWM-controlled servos.

[noitemsep,topsep=0pt]

- Headers: Five 1 × 3 headers (J1–J5) supplying 5V, GND, and a logic signal.
- Logic Control: Driven by Pico W pins GPIO0 through GPIO4.
- Protection: Each PWM signal line is in series with a 220 Ω current-limiting resistor (R3–R7) to protect the microcontroller from inductive kickback or stall-current faults.

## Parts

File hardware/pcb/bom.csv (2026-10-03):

Ref | Qty | Value | Footprint | Role
A1 | 1 | Raspberry Pi Pico W | RaspberryPi_Pico_W_SMD_HandSolder | Microcontroller
U1 | 1 | TPS5430DDA | SO-PowerPAD-8 | 12 V to 5 V buck converter
U2 | 1 | AMS1117-3.3 | SOT-223 | 3.3 V LDO
U3 | 1 | MAX31865xAP | SSOP-20 | RTD-to-digital converter
U4 | 1 | SHT4x | DFN-4 1.5x1.5 | Humidity sensor
D1 | 1 | Schottky diode | 0603 (see design review notes) | Buck catch diode
L1 | 1 | 33 uH | 0603 (see design review notes) | Buck inductor
C2 | 1 | 0.01 uF | 0603 | Buck bootstrap
C3 | 1 | 220 uF | CP_Elec_8x6.9 | Bulk output capacitor
C4,C5,C6 | 3 | 10 uF | 0603 | Buck input / LDO input / LDO output
C7,C8 | 2 | 0.1 uF | 0603 | Sensor decoupling
R1 | 1 | 31.6 k | 0603 | Buck feedback (upper)
R2 | 1 | 10 k | 0603 | Buck feedback (lower)
R3,R4,R5,R6,R7 | 5 | 220 ohm | 0603 | Servo signal series resistors
R8 | 1 | 4.3 k 0.1 % | 0603 | MAX31865 reference resistor
R9,R10 | 2 | 10 k | 0603 | I2C pull-ups
J1,J2,J3,J4,J5 | 5 | 1x3 pin header | 2.54 mm | Servo outputs
J6 | 1 | 1x4 pin header | 2.54 mm | PT1000 4-wire input
H1,H2,H3,H4 | 4 | Mounting hole |  | Board mounting
EXT | 1 | PT1000 Class A probe |  | Temperature sensor (external)
EXT | 1 | 12 V DC supply |  | Board power (external)

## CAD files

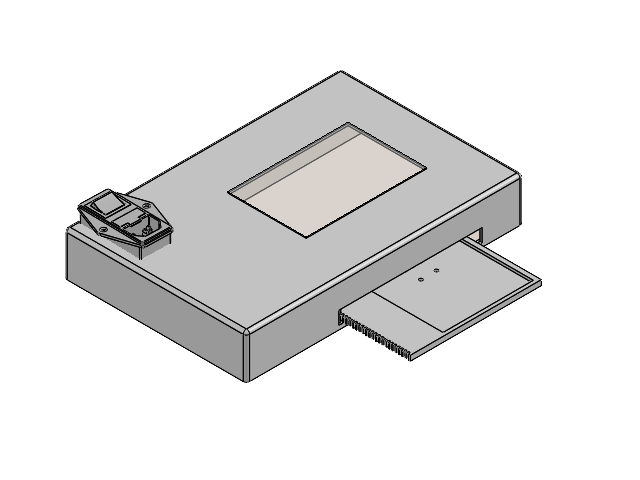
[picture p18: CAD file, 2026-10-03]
hardware/cad/solidworks/Main_Incubator_Assembly.SLDASM
Plate_Carriage_Tray
Inner_Chamber_Base
Motor_Bracket
Pinion_Gear

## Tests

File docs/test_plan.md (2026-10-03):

# Validation plan

Nothing below has been run yet. These are the acceptance tests planned for the build; results will go in `docs/results/`.

## 1. Electronics bring-up (bench)
1. Visual inspection, continuity and short checks (12 V, 5 V, 3.3 V, GND).
2. Power-up with a current-limited supply. Check 5 V is near 5.0 V and 3.3 V is near 3.3 V, under no load and with one servo moving.
3. Scope the buck output ripple under servo load.
4. Flash `firmware/pico`, confirm the SHT4x reads at address 0x44.
5. Replace the PT1000 with fixed precision resistors (for example 1000 ohm = 0 C, 1385 ohm = 100 C) and confirm the MAX31865 readings.

## 2. Temperature
- Sensor accuracy: compare the PT1000 chain against a calibrated reference thermometer at about 25, 37 and 40 C.
- Chamber: time to reach 37 C, overshoot, and steady-state stability over 24 h with the tray retracted.
- Tray cycle: temperature recovery time after an eject/retract cycle.

## 3. Humidity
- Hold RH near 95 % for 24 h; log RH and check for condensation on the optical window.

## 4. CO2 and N2 (when the gas route is decided)
- Verify the setpoint against a reference NDIR sensor, then log drift over several days.

## 5. Tray mechanics
- Positional repeatability over at least 100 eject/retract cycles (dial gauge or camera).
- Speed and smoothness; check there is no jamming or plate slip.
- Log gear wear on the printed rack and pinion.

## 6. Biological test (with the biologists)
- Culture stem cells in the chamber for several days, compared with a standard incubator control.
- Endpoints (for example viability and morphology) to be agreed with the lab.

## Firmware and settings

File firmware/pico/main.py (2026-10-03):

"""Incubator controller main loop (MicroPython on Raspberry Pi Pico W).

Every SAMPLE_PERIOD_S it reads the PT1000 (MAX31865) and SHT4x, optionally runs a PID
on a heater output, and prints one JSON line over USB serial. It also accepts text commands:
    EJECT | RETRACT | SET_TEMP <C> | STATUS
"""
import sys
import time
import json
import select

import config
import max31865
import sht4x
from servo import Servo
from pid import PID

try:
    from machine import Pin, PWM
except ImportError:  # allows importing for static checks on a PC
    Pin = PWM = None


def main():
    rtd = max31865.make(config)
    rh_sensor = sht4x.make(config)
    tray = Servo(config.SERVO_PINS[config.TRAY_SERVO])
    tray.write_angle(config.TRAY_ANGLE_RETRACTED)
    tray_state = "retracted"

    heater = None
    if config.PIN_HEATER is not None:
        heater = PWM(Pin(config.PIN_HEATER))
        heater.freq(config.HEATER_PWM_HZ)
        heater.duty_u16(0)
    pid = PID(kp=0.15, ki=0.01, kd=0.0)  # placeholder gains - tune on the real chamber
    setpoint = config.TARGET_TEMP_C

    poll = select.poll()
    poll.register(sys.stdin, select.POLLIN)
    last = time.ticks_ms()

    while True:
        # ---- commands from the PC ----
        if poll.poll(0):
            parts = sys.stdin.readline().strip().split()
            cmd = parts[0].upper() if parts else ""
            if cmd == "EJECT" and tray_state != "ejected":
                tray.sweep(config.TRAY_ANGLE_EJECTED, config.TRAY_MOVE_TIME_S)
                tray_state = "ejected"
            elif cmd == "RETRACT" and tray_state != "retracted":
                tray.sweep(config.TRAY_ANGLE_RETRACTED, config.TRAY_MOVE_TIME_S)
                tray_state = "retracted"
            elif cmd == "SET_TEMP" and len(parts) == 2:
                setpoint = max(20.0, min(40.0, float(parts[1])))
                pid.reset()

        # ---- periodic sample ----
        now = time.ticks_ms()
        if time.ticks_diff(now, last) >= config.SAMPLE_PERIOD_S * 1000:
            dt = time.ticks_diff(now, last) / 1000.0
            last = now
            msg = {"t": time.time(), "tray": tray_state, "setpoint_c": setpoint}
            try:
                temp = rtd.temperature_c()
                msg["temp_c"] = round(temp, 3)
                duty = pid.update(setpoint, temp, dt) if tray_state == "retracted" else 0.0
                if heater:
                    heater.duty_u16(int(duty * 65535))
                msg["heater"] = round(duty, 3)
            except OSError as e:
                msg["rtd_error"] = str(e)
                if heater:
                    heater.duty_u16(0)        # fail safe: heater off on sensor fault
            try:
                _, rh = rh_sensor.read()
                msg["rh_pct"] = round(rh, 1)
            except OSError as e:
                msg["rh_error"] = str(e)
            print(json.dumps(msg))
        time.sleep_ms(20)


main()

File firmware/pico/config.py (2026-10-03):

"""Pin map and constants for the stage-top incubator control PCB (Raspberry Pi Pico W).

Pins marked VERIFIED come from the PCB hardware documentation / schematic.
Anything marked TODO is not on the current board and must be decided with the lab.
"""

# --- SPI0 -> MAX31865 RTD-to-digital converter (U3) --- VERIFIED
SPI_ID = 0
PIN_SPI_MISO = 16
PIN_SPI_CS = 17
PIN_SPI_SCK = 18
PIN_SPI_MOSI = 19

# --- I2C0 -> SHT4x humidity / temperature sensor (U4), 10 k pull-ups on board --- VERIFIED
I2C_ID = 0
PIN_I2C_SDA = 8
PIN_I2C_SCL = 9
SHT4X_ADDR = 0x44

# --- PWM servo headers J1..J5 (5 V, GND, signal via 220 ohm) --- VERIFIED
SERVO_PINS = {"J1": 0, "J2": 1, "J3": 2, "J4": 3, "J5": 4}
TRAY_SERVO = "J1"           # which header drives the rack-and-pinion tray (assignment is a choice)

# --- MAX31865 / PT1000 --- VERIFIED
RTD_NOMINAL_OHM = 1000.0    # PT1000
RTD_REF_OHM = 4300.0        # R8, 4.3 k 0.1 %
RTD_WIRES = 4               # 4-wire (FORCE+/-, RTDIN+/-)
MAINS_FILTER_HZ = 50        # 50 Hz mains (Europe / India)

# --- Control targets (from the design proposal) ---
TARGET_TEMP_C = 37.0
TARGET_RH_PCT = 95.0
TARGET_CO2_PCT = 5.0        # CO2 control is external / not on this PCB yet

# --- Tray calibration: measure on the real assembly, then edit --- TODO
TRAY_ANGLE_RETRACTED = 0.0  # servo angle (deg) with tray fully inside
TRAY_ANGLE_EJECTED = 180.0  # servo angle (deg) with tray fully out
TRAY_MOVE_TIME_S = 2.0      # time to sweep between the two positions

# --- Heater output (NOT on the current PCB; needs an external MOSFET/SSR driver) --- TODO
PIN_HEATER = None           # set to a free GPIO number once a driver stage exists
HEATER_PWM_HZ = 2           # slow PWM / time-proportioning for an SSR

SAMPLE_PERIOD_S = 2.0

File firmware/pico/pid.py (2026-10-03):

"""Small PID controller with output clamping and anti-windup (conditional integration)."""


class PID:
    def __init__(self, kp, ki, kd, out_min=0.0, out_max=1.0):
        self.kp, self.ki, self.kd = kp, ki, kd
        self.out_min, self.out_max = out_min, out_max
        self._i = 0.0
        self._prev = None

    def reset(self):
        self._i, self._prev = 0.0, None

    def update(self, setpoint, measurement, dt):
        err = setpoint - measurement
        d = 0.0 if self._prev is None else (err - self._prev) / dt
        self._prev = err
        out = self.kp * err + self._i + self.kd * d
        if self.out_min < out < self.out_max:           # integrate only when not saturated
            self._i += self.ki * err * dt
        return max(self.out_min, min(self.out_max, out))

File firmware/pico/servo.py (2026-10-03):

"""PWM servo helper (50 Hz, 500-2500 us pulse)."""
import time
from machine import Pin, PWM

_PERIOD_US = 20000


class Servo:
    def __init__(self, pin, min_us=500, max_us=2500, max_deg=180.0):
        self.pwm = PWM(Pin(pin))
        self.pwm.freq(50)
        self.min_us, self.max_us, self.max_deg = min_us, max_us, max_deg
        self.angle = None

    def write_us(self, pulse_us):
        self.pwm.duty_u16(int(pulse_us * 65535 / _PERIOD_US))

    def write_angle(self, deg):
        deg = max(0.0, min(self.max_deg, deg))
        self.write_us(self.min_us + (self.max_us - self.min_us) * deg / self.max_deg)
        self.angle = deg

    def sweep(self, target_deg, duration_s, steps=50):
        """Move smoothly (linear ramp) so the tray does not jerk the sample plate."""
        start = self.angle if self.angle is not None else target_deg
        for i in range(1, steps + 1):
            self.write_angle(start + (target_deg - start) * i / steps)
            time.sleep(duration_s / steps)

    def release(self):
        self.pwm.duty_u16(0)

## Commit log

2026-10-03 Initial commit: bench-top cell incubator
    [Main_Incubator_Assembly.SLDASM, PCB_EMBL.kicad_sch, bom.csv]
2026-10-05 Revise README for clarity and additional details
    Updated temperature and humidity references to use proper symbols. Added new images and sections for system architecture, sensors, and communication protocols.
